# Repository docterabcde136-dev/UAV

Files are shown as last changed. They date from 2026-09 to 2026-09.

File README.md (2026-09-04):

# UAV

## 项目简介

基于 STM32F405 的四轴无人机飞控系统，集成 LQR 与 PID 控制算法、姿态解算、FreeRTOS 实时操作系统、DShot 电调驱动、IMU 多传感器融合（陀螺仪/加速度计）、蓝牙与 PS2 遥控、光流定高，配套 MATLAB/Simulink/Simscape 仿真验证与 Keil MDK 嵌入式开发完整资料。

STM32F405-based quadcopter flight control system integrating LQR and PID control algorithms, attitude estimation, FreeRTOS real-time operating system, DShot ESC driver, IMU multi-sensor fusion (gyroscope/accelerometer), Bluetooth and PS2 remote control, and optical flow altitude hold, with complete MATLAB/Simulink/Simscape simulation verification and Keil MDK embedded development resources.

## 目录结构

```

无人机 /

├── 四轴无人机 /

│   ├── 程序源码 /

│   │   ├── keil 工程 /                 # Keil MDK 工程（LQR / PID / 电调例程）

│   │   └── MATLAB 程序 /        # MATLAB 仿真与算法验证

│   ├── 传感器手册 /                   # 各传感器数据手册

│   ├── 原理图 /                          # 飞控板原理图

│   ├── 飞行器油门拟合文件 /    # 油门曲线拟合数据

│   └── *.pdf                               # 开发手册、使用手册、调试经验

└── 初学者复刻 /                        # 入门级复刻资料与烧录工具

```

## 开发环境

- **IDE**：Keil MDK 5

- **芯片**：STM32F405RGT6

- **系统**：FreeRTOS

- **仿真**：MATLAB / Simulink / Simscape

## 大文件下载

以下文件体积较大，未纳入 git 版本管理，请通过百度网盘下载：

| 文件 | 大小 | 说明 | 下载链接 |

| LQR.avi | 353 MB | Simscape 四轴飞行器 LQR 控制仿真演示视频 | https://pan.baidu.com/s/13S9hLy8eEmibUFdEDGfKNA?pwd=5m56  |

| 无人机配套软件工具.zip | ~116 MB | 串口调试助手、虚拟串口、无线烧录助手、蓝牙透传软件、FlyControl APP 等 | https://pan.baidu.com/s/14PjQdfBVtd2VivTcREuWbg?pwd=459s  |

## 编译说明

1. 使用 Keil MDK 5 打开 `程序源码/keil工程/LQR/MDK-ARM/Fly_LQR.uvprojx`

2. 选择对应目标编译生成固件

3. 使用无线烧录助手或 ST-Link 烧录到飞控板

## 注意事项

- 编译产物（`.o`、`.crf`、`.axf` 等）已通过 `.gitignore` 过滤，clone 后需自行编译

- 第三方软件工具不纳入 git，请到上方百度网盘链接下载

- 仿真视频不纳入 git，请到上方百度网盘链接下载

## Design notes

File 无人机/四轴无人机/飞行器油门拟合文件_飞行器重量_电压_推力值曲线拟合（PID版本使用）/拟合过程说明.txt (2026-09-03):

1.通过电子秤，采集飞行器在 10V、10.5V、11V、11.5V、12V、12.5V 的电压下，油门在 48 - 1148 范围内的推力值（其中48-1148油门，每间隔50油门采集1次推力参数）

2.将上述采集到的数据表，写入python文件进行拟合，主要输出以下公式：输入当前的电压值、输入的飞行器重量，计算出需要多少油门值才可以保持飞行器的推力与自身重量持平。

3.安装好python所需的各类库文件，运行py文件，输出拟合公式。

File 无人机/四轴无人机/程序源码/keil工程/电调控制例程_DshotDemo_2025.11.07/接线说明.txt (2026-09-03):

本例程使用STM32F405单片机作为案例
PC6  --- 电调1 PWM信号引脚
PC7  --- 电调2 PWM信号引脚
PC8  --- 电调3 PWM信号引脚
PC8  --- 电调4 PWM信号引脚

本案例中电调固件版本为BlueJay v0.21

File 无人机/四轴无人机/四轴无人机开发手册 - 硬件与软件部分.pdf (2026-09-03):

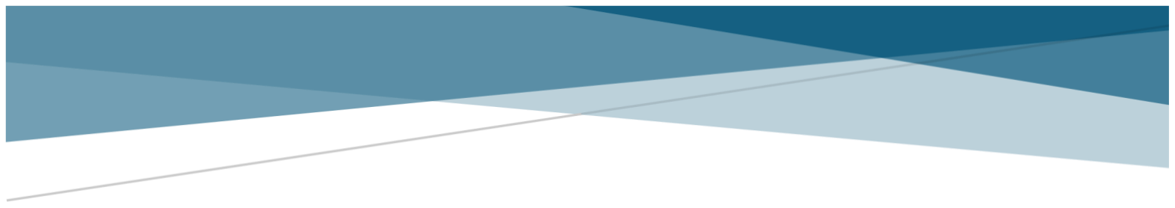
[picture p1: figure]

# STM32F4 四轴飞行器开发手册

## 硬件与软件部分

### 光电 209 实验室

摘要

本文档对四轴飞行器的硬件设计、软件框架作讲解与介绍，助力于读者能快速理解飞 行器的软件结构和所有功能的实现原理。文档内容不包括四轴飞行器的控制原理与算 法部分，该部分内容请查看资料内《四轴无人机开发手册 - 原理与算法部分》文档。

目录

1.软件资源概览

本产品使用到的主控芯片为 STM32F405RGT6，使用到的资源以及作用如 下介绍：
ADC1_IN1: ADC1 通道 1，用于采集电池的输入电压，监测电池电量 TIM6: 计数定时器，用于 FreeRTOS 系统调试
TIM8: 定时器 8 所有通道，PWM 输出，用于驱动电调控制电机 TIM7: HAL 库时基
SysTick: FreeRTOS 系统时基
I2C1: | 硬件 IIC1，用于与陀螺仪通信，获取陀螺仪数据
USART1: | 调试串口，同时也是程序烧录口
USART2: | 串口 2，与雷达模块通信
USART3: | 串口 3，与光流模块通信，获取光流传感器数据
USART4: | 串口 4，与蓝牙模块通信，用于手机 APP 控制与查看波形功能
UART5: | 串口 5，与激光测距模块 STP23L 通信，获取高度信息
USB_OTG_FS: | 全速 USB 接口，用于获取 PS2 手柄数据
GPIO: | 普通 GPIO,用于 LED、蜂鸣器、OLED 等功能。其中 OLED 为预留
接口。

2.软件框架设计说明

为保证四轴飞行器运行的实时性以及 CPU 资料的合理分配使用，整体软件 框架基于 FreeRTOS 设计，运行框架如图所示：

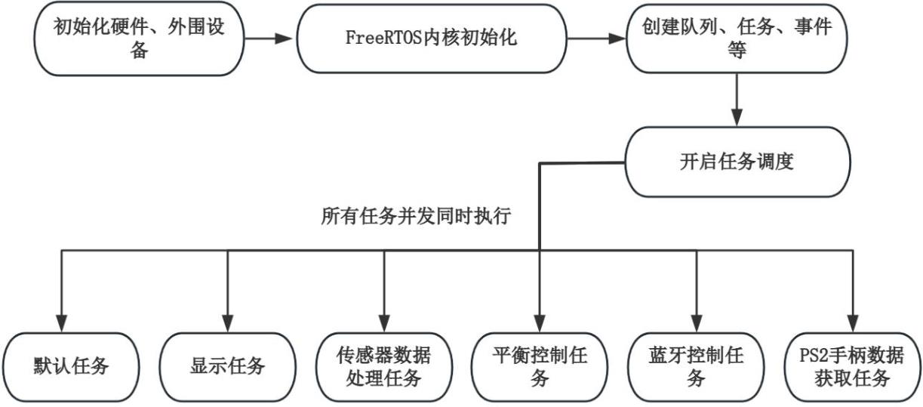
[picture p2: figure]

对于具体的任务优先级配置，可查看文件 freertos.c 中的 MX_FREERTOS_Init()函数。在任务创建并开始调度后，每个任务将会同时运行。

2.1 默认任务

在默认任务内，会创建 USB 手柄接收任务，并使能各个传感器的 DMA 接 收，以便实时获得数据。在默认任务完成后，会删除自身以节省资源空间。任务

名称为 voidStartDefaultTask(void*argument)。整体运行逻辑如下图所示。

2.2 显示任务

显示任务主要负责将飞行器的实时状态进行上传。可以通过程序来选择上传 到手机 APP 或 minibalance 上位机。上传的数据包括电池电压、欧拉角、飞行高 度等数据，具体内容可以在程序中进行自定义调节。显示任务函数名为

ShowTask(void*param)。
由于显示任务为调试属性，所以将其优先级配置为较低。只有在其他控制任 务阻塞时，才会执行显示任务。其任务逻辑如下图所示。

2.3 传感器数据处理任务

该任务主要负责接收解析激光测距模块、雷达模块的数据。其触发机制如下： 空闲时该任务是阻塞状态，不会运行。当测距模块或雷达模块数据到来时，由 DMA 将数据放入队列中，当队列中存在数据时，调度器会唤醒该任务进行数据 处理与解析。解析后的数据将会提供给控制任务使用。

任务名称为 voidSensorHandleTask(void*param)，其逻辑如下图所示。

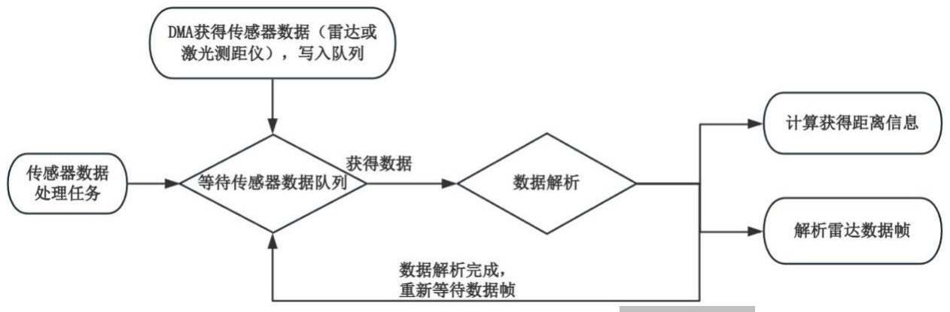
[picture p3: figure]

其中 STP23L 激光测距模块解析数据的过程在 | bsp_stp23L.c | 文件内。雷达解

析数据过程在 bsp_stl06n.c 文件内。

2.4 平衡控制任务

该任务是四轴飞行器控制的核心部分，内部包含了陀螺仪数据的获取与处理、 高度数据的使用与处理、雷达数据使用与处理、LQR 控制器、四轴飞行器的状态 设置与获取等内容。
值得注意的是，该任务为主要的核心部分，以 200Hz 的频率运行。四轴的平 稳控制需要保证该任务频率足够准确。在设计其他模块或任务时，均需要考虑任 务优先级以及某些任务是否长时间占用 CPU 时间等问题。同时该任务内也加入 了一个外部的频率检测器，可以用过该检测器来检测任务频率是否准确，其内容 如下所示：

g_readonly_BalanceTaskFreq=debug->UpdateFreq(&debugPriv);
如果加了其他 DIY 传感器或者功能，可以通过监测

g_readonly_BalanceTaskFreq 变量的输出来检查当前的任务频率是否满足要 求，正常该值输出为 200，单位是 Hz。若为其他数值，则说明控制任务的频率受 到了干扰。

控制任务的名称为 voidbalance_task(void*param)，其运行逻辑如下所示：

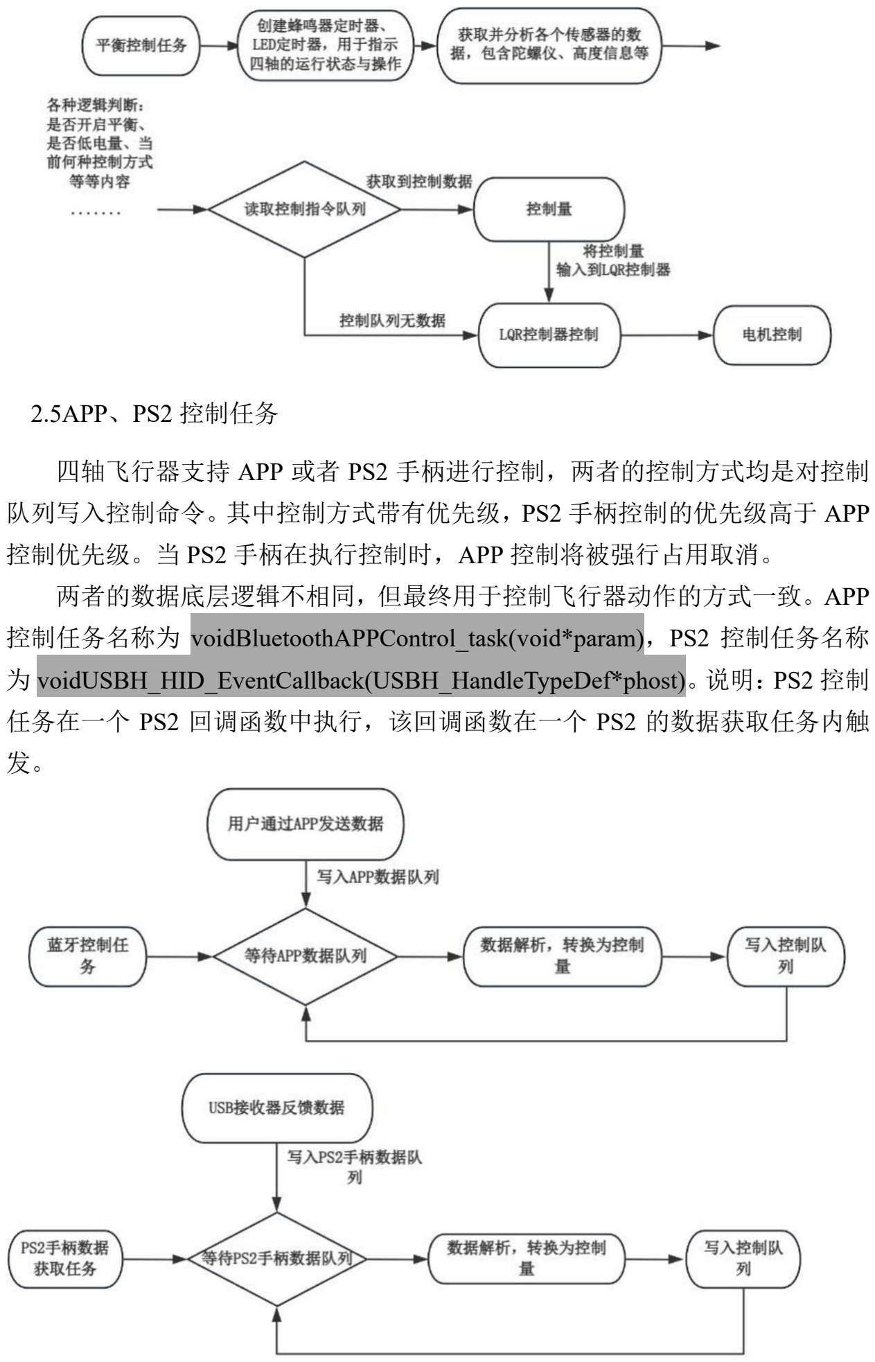
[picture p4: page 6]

2.5APP、PS2 控制任务

四轴飞行器支持 APP 或者 PS2 手柄进行控制，两者的控制方式均是对控制 队列写入控制命令。其中控制方式带有优先级，PS2 手柄控制的优先级高于 APP 控制优先级。当 PS2 手柄在执行控制时，APP 控制将被强行占用取消。 两者的数据底层逻辑不相同，但最终用于控制飞行器动作的方式一致。APP

控制任务名称为 voidBluetoothAPPControl_task(void*param)，PS2 控制任务名称

为 voidUSBH_HID_EventCallback(USBH_HandleTypeDef*phost)。说明：PS2 控制 任务在一个 PS2 回调函数中执行，该回调函数在一个 PS2 的数据获取任务内触 发。

2.6 雷达数据处理任务

在传感器数据处理任务中，会判断是否完成 1 圈雷达数据的接收。在完成 1 圈雷达数据接收后，将会把数据写入队列，让雷达数据处理任务运行，雷达数据 处理任务的内容是将雷达的数据通过算法处理成飞行器的坐标数据。

雷达接收的任务名称为 voidSensorHandleTask(void*param)，雷达点云处理算

法任务名称为 voidCoordinateHandleTask(void*param)。

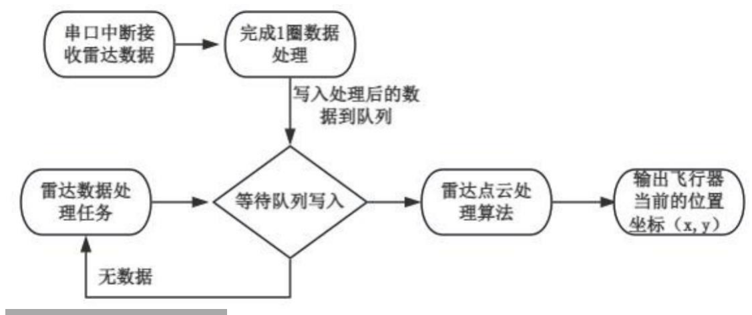
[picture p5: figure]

CoordinateHandleTask，避障功能，具体表现为：雷达的前后左右四个方向， 有一个方向有障碍物靠近时，飞行器就会往相反的方向运动，并发出蜂鸣器提示。 此功能为实验性功能，后续可以根据现有内容继续优化，已完成更好的避障效果。

2.7 光流数据处理中断

光流传感器的原始数据直接在串口中断内进行解析，频率 50Hz。具体过程 为：光流完成初始化后，将通过一定的格式主动上报数据，每一帧数据上报完成 后，就会进入串口空闲中断，在此中断内解析处理 DMA 搬运的数据。 拿到原始数据后，在平衡控制任务将原始数据与陀螺仪数据进行融合增加稳 定性，最终把融合后的数据用于位置控制。

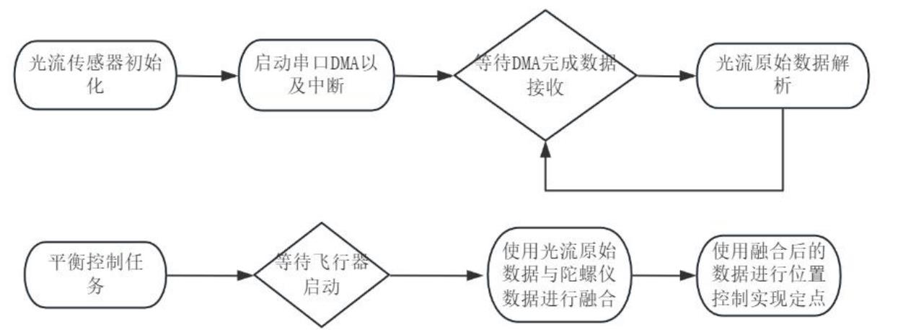
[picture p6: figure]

3.硬件与软件实现细节

3.1 陀螺仪

1 陀螺仪电路设计

陀螺仪是四轴飞行器的核心传感器，本产品采用 InvenSense 公司的 ICM20948，原理图如图所示。其中 SCL、SDA 连接至硬件 IIC1 接口，中断输出 引脚 INT1 连接到普通的 IO。在本产品中未使用陀螺仪的中断功能，仅获取其原

始数据使用。

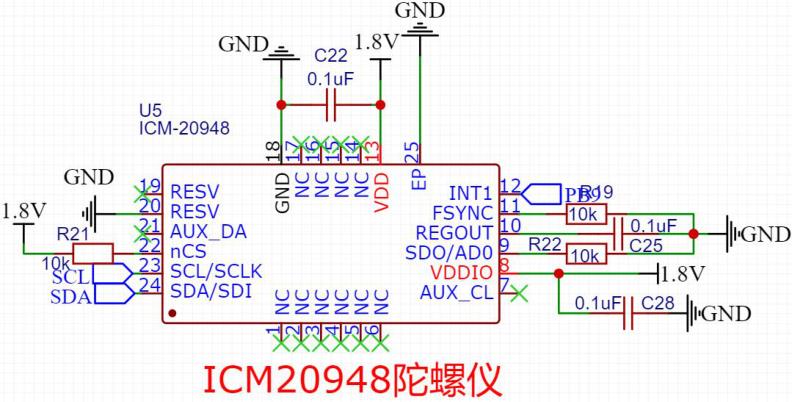
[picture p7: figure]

2 陀螺仪数据获取

ICM20948 最大支持 400kHz 的 IIC 通信速率，故 IIC 总线做如下图配置，更

多细节可自行查看 ioc 配置文件：
为了方便移植以及使用模拟 iic，在软件中对 iic 接口做了以下的封装，在该

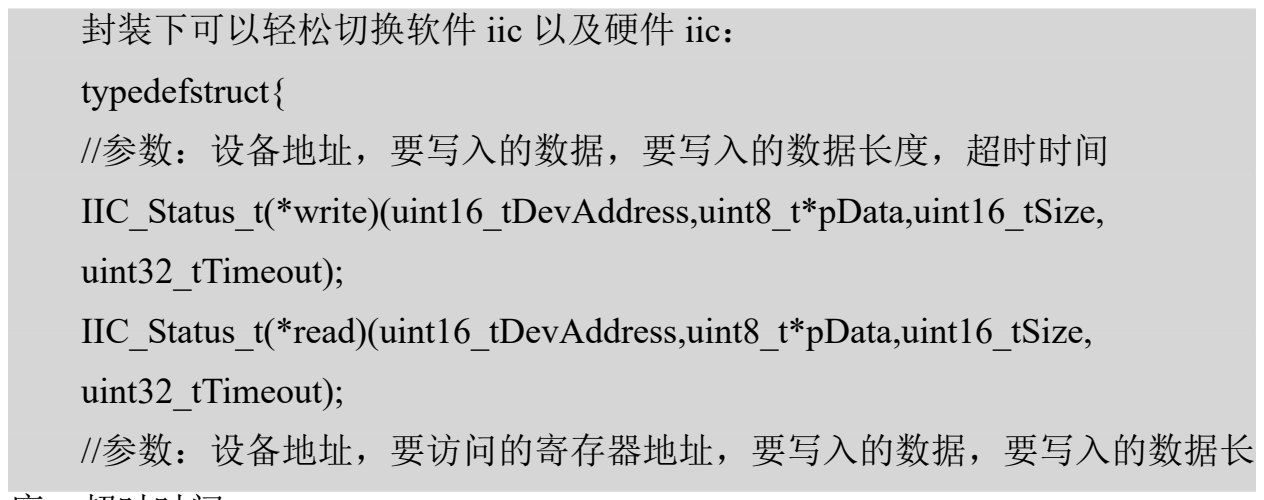
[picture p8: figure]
封装下可以轻松切换软件 iic 以及硬件 iic：; typedefstruct{; //参数：设备地址，要写入的数据，要写入的数据长度，超时时间; uint32_tTimeout);; //参数：设备地址，要访问的寄存器地址，要写入的数据，要写入的数据长

IIC_Status_t(*write)(uint16_tDevAddress,uint8_t*pData,uint16_tSize,

IIC_Status_t(*read)(uint16_tDevAddress,uint8_t*pData,uint16_tSize,

度，超时时间

硬件初始化完毕 iic 后，再将硬件 iic 的接口函数挂载到上述自定义接口中， 即可完成 iic 的所有初始化步骤。至此已经可以顺利使用 iic 与陀螺仪进行通信

了，初始化部分可在 bsp_imc.c 文件内查看函数 staticuint8_t ICM20948_Init(void)。 完成 imu 初始化后，后续主要通过两个函数来实现 imu 的原始数据以及姿 态解算：

staticvoidImuUpdate(IMU_DATA_t*data)：获取 IMU 的 9 轴原始数值

staticvoidattitudeUpdate(IMU_DATA_timudata,ATTITUDE_DATA_t*attitude) ： 使用 imu 的原始值进行姿态解算，获得欧拉角。该函数使用显示互补滤波算法， 内部的实现细节可查看《四轴无人机开发手册-原理与算法部分》文档。

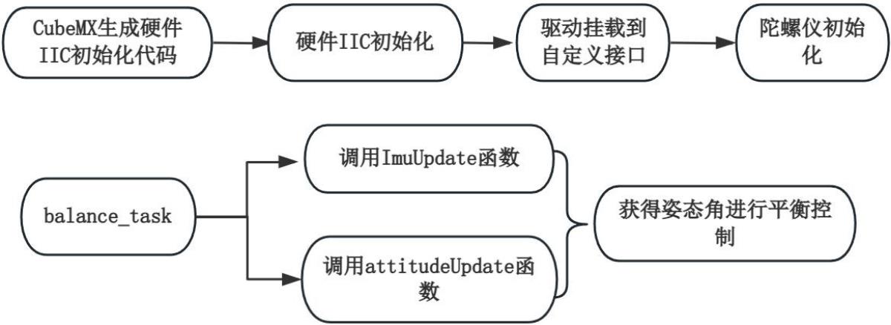
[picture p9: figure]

3.2 激光测距

激光测距模块使用 STP23-L，该传感器的详情在资料文件夹《传感器手册》 中可查看。STP23-L 通过串口输出数据，波特率为 230400，数据以点云的形式输 出。1 个点云数据内容包含测量距离、信号强度、置信度等信息。其输出频率为 10Hz，1 帧数据内包括 12 个点云信息。

高度数据通过串口接收，最终通过 bsp_stp23L.c 文件内的

stp23L_getdistance_callback 进行接收以及数据解码。其接收过程如下图所示：

3.3 电量检测

电量检测主要通过测量电池的输入电压来实现。本产品使用磷酸铁锂电池电 池，标称电压 12.6V，截至电压 10V。在飞行器运行的过程中，由于飞行器 供电线长的关系(2 米)，实测压降为 0.8V 左右。例如飞行器电池电压有 10.8V， 在飞行器运行期间，能够输入到飞行器内的电压为 10.8-0.8=10V。为了保证有足

够的电量进行飞行，在程序内部设定了电量低的保护，当电池电压低于 10.8V 时， 将不允许启动。

1 电压测量电路实现

在电池输入处，串联了一个 100k 和 10k 的电阻实现分压，并使用 ADC 相 关的引脚进行模拟量采集，此处为 PA1，如下图所示。 根据简单的分压公式可得知，测量点处的电压为：Vin=VADC×11
ADC 测量引脚电压范围在 0~3.3V，对应 ADC 采样值 0~4095，可得出最终

的输入电压公式为：Vin=ADC 采样原始值/4095×3.3×11

2 程序实现

为确保不影响系统的实时性，ADC 配置为软件触发、连续采集，并使用 DMA

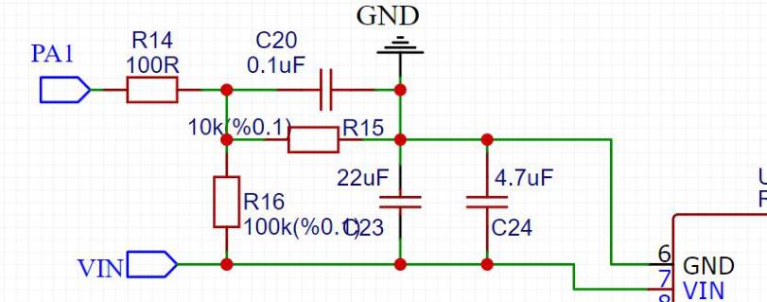
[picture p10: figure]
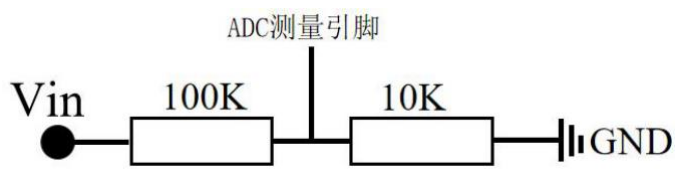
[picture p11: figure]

循环搬运数据，不占用 CPU 资源。为保证采样的准确性，采用时配置了最大的 采样周期，同时让 DMA 搬运到一个长度为 80 的数组中，最终取平均值计算。 具体的配置可查看 ioc 配置文件，程序的实现在 bsp_adc.c 文件内。最终的输入

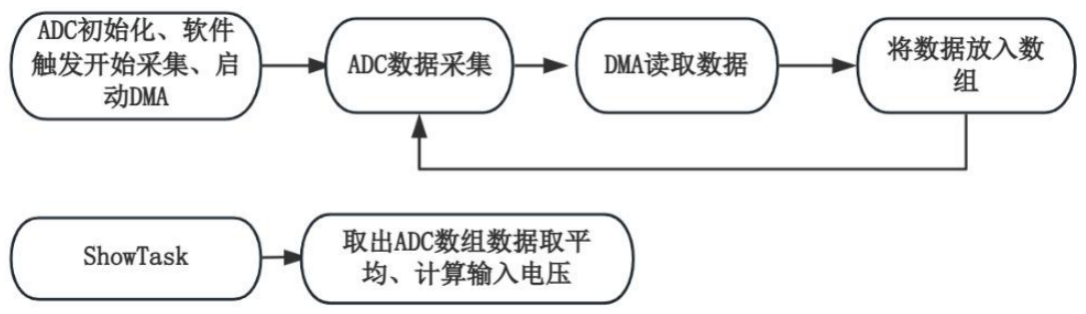
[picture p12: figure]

电压计算由显示任务完成，其处理的内容主要是在数组中取出数据取平均，然后 根据上述提到的公式计算出输入电压。

3.4 电机控制

1 硬件部分

电机控制的硬件部分主要是引出 TIM8 的 4 个通道引脚，作为一个接口与电

调连接，如下图所示。飞控与电调的连接如下：

PC6---E1（E1~E4 为电机控制信号线，ADC 用于电调电流采集）

PC7---E2

PC8---E3

PC9---E4

PB1---ADC
电调负责的工作：将主控芯片发过来的信号解析，最终转换为油门的大小， 控制无刷电机旋转。
飞控板的工作：将 LQR 控制器输出的信号转化为油门值，通过 PWM 引脚

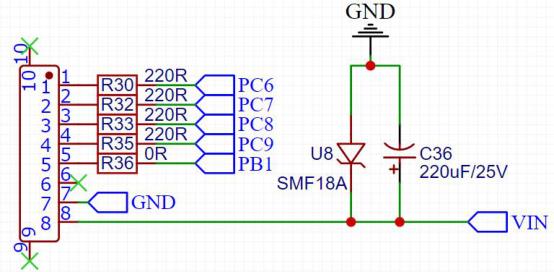
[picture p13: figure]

发送到电调。

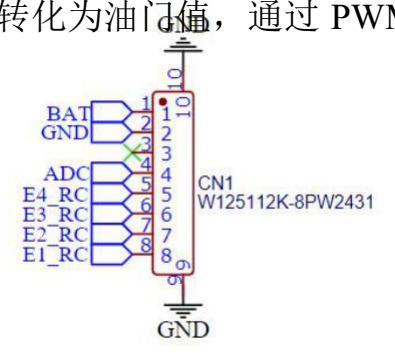
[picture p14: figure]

飞控板与电调通信的协议为 Dshot300。下面简述 Dshot 协议的一些基本内

容：目前 Dshot 协议常见类型有 Dshot150、Dshot300、Dshot600 和 Dshot1200。 后面的数字代表在通信过程中，每秒传输多少 kbit，类似于串口的波特率。例如 本产品中使用 Dshot300 协议，代表飞控每秒可传输 300kbit 数据到电调。
在 Dshot 协议中，一个周期脉冲表示一个 bit，发送的数据位 0 或者 1 则通 过一个周期内的占空比来表示。所以 Dshot 与 PWM 有如下的关系：Dshot 协议 的速度类型决定 PWM 的频率，Dshot 发送的数据位 0 或者 1 决定 PWM 的占空 比。
Dshot 协议中的 0 或者 1 的占空比对应关系如下图：

逻辑 1 对应 PWM 占空比 75%

逻辑 0 对应 PWM 占空比 37.5%

Dshot 协议在通信时，一帧数据共有 16 个 bit 构成，其中前 11 位是油门信 号，可表示的范围是 0~2047。第 12 位是命令请求或者命令设置使能位，后 4 位

是校验位。
油门信号：在油门值中，0~47 的数值范围用于一些命令的设置，比如设置电 调的 LED 指示灯、设置电机的旋转方向等功能。所以真实的油门值信号从 48 开 始，48 表示最低油门，电机不会旋转；2047 表示满油门，电机将会以最大速度 运行。
命令请求位/设置使能位：如果需要对电调进行设置时，例如上述提到的修 改电机旋转方向或 LED 指示灯，则需要把这个位置 1。若需要对电机进行控制 （设置 48~2047 油门值），需要将此位设置为 0。
校验位：校验位是将前 12 位数据分为 3 组，每组 4bit，进行异或校验。 假设当前有一个 12 位的 SendData 数值需要校验，则校验方式为：

csum=(SendData^(SendData>>4)^(SendData>>8))&0xf
下面一帧完整的 dshot 数据演示，假设当前需要设置油门值

1046(10000010110b)，则命令使能位应该位 0，则可计算到校验位为 0x06(0110b), 数据帧如下图所示：

更多 Dshot 内容,推荐参考网址：DSHOTintheDark–dmrlawson (https://dmrlawson.co.uk/index.php/2017/12/04/dshot-in-the-dark/)
在简单了解上述 Dshot 的通信协议与原理后，就可以对飞控板进行定时器的 配置了。首先是 PWM 的配置频率，这里使用的是 Dshot300 协议，速率为 300kbit/s，

也就是 PWM 每秒输出 300k 个脉冲，故 PWM 配置为 300000Hz。
飞控板使用的是 TIM8 作为通信的定时器，其主频为 168MHz，为了方便计 算，将定时器的预分频系数配置为 0。可算的自动重装载值配置应为 559。

将 TIM8 配置为 PWM1 输出，向上计数。要实现发送 dshot 的 0 和 1 指令 时，只需要修改定时器的 CCRx 寄存器即可。当需要发送逻辑 1 时，可通过配置 对应通道的 CCRx 寄存器输出 75%的占空比；需要发送逻辑 0 时，配置对应通道 的 CCRx 寄存器输出 37.5 占空比。

根据上述的配置，已经可以正确的向电调发送 0 和 1 的数据位了，此时需要 一个函数，直接将需要发送的油门值进行解析，然后通过 PWM 的形式发送到电 调中。本产品使用 DMA 的方式，将解析后的数据搬运到定时器对应通道的 CCRx

寄存器内，实现与电调通信，具体内容可在 bsp_dshot.c 文件内的 pwmWriteDigital 函数查看。其核心部分是将 0 与 1 通过 CCRx 寄存器的值表示，以及通过 DMA

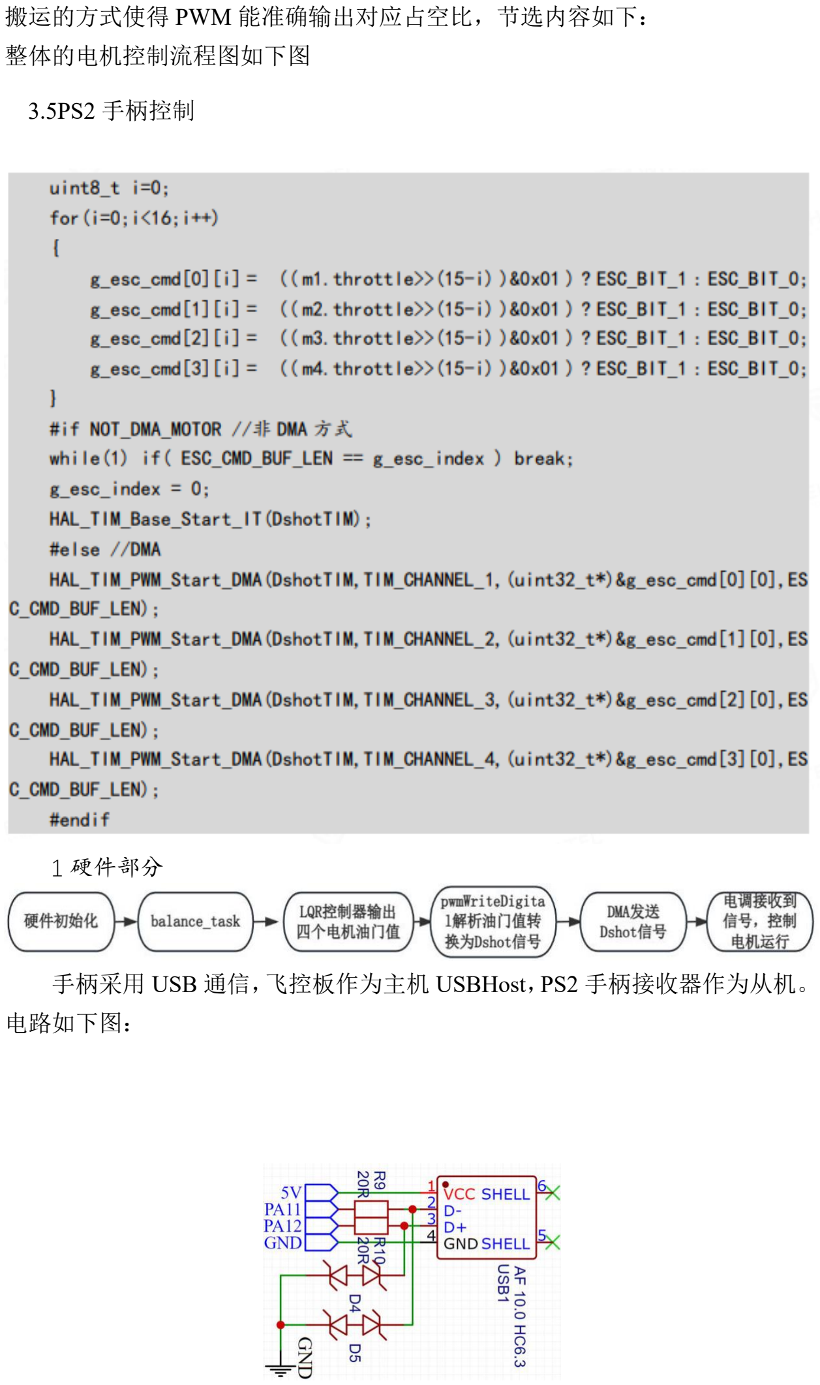
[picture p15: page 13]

搬运的方式使得 PWM 能准确输出对应占空比，节选内容如下： 整体的电机控制流程图如下图

3.5PS2 手柄控制

1 硬件部分

手柄采用 USB 通信，飞控板作为主机 USBHost，PS2 手柄接收器作为从机。 电路如下图：

2 软件部分

在 CubeMX 中，将 USB_OTG_FS 全速设备使能，如下图所示：

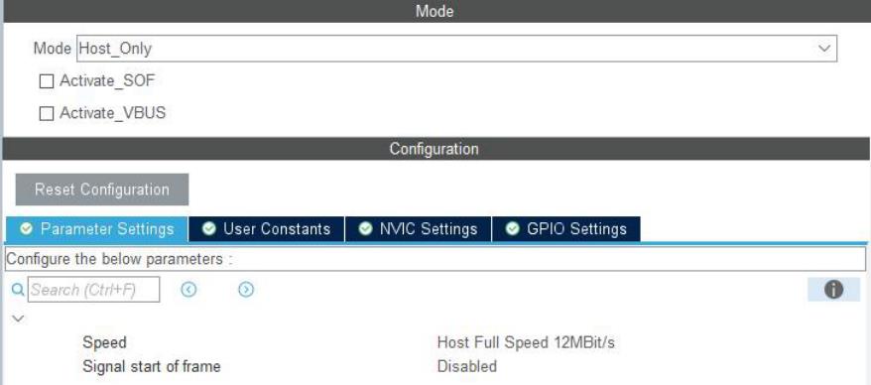
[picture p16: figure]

使能 USBOTG 后，在中间件里面配置 USB 设备的类型，手柄类型是 HID。 本产品使用的无线 PS2 手柄内置两种模式，一种为 PC 模式，一种 Android 模式， 两种模式是不同的 HID 设备类型，所以在最大支持的 HID 设备类中，配置为 2。 另外 PS2 设备输出的数据长度较长，需要给存放数据的 Buffer 配置较大长度， 这里为 1024bytes。此外使用到了 FreeRTOS，所以在 RTOS 配置栏需要配置优先 级，以及任务的栈大小，如下图所示。

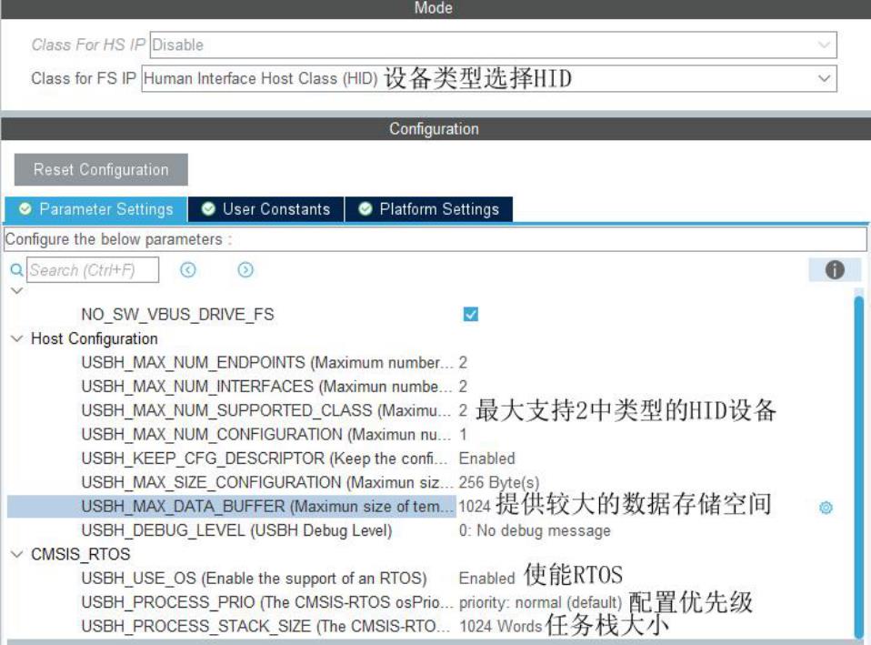
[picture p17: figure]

完成 CubeMX 配置后，需要手动创建 PS2 的 HID 类，并提供接口初始化函 数、数据请求函数、数据解析函数等内容，此部分内容可参考官方提供的

usbh_hid_keybd.c 或 usbh_hid_mouse.c 学习。PS2 手柄相关的细节位于 bsp_ps2.c 文件内。在创建完 PS2 手柄的 HID 类后，需要将设备注册到 USB HOST，注册

以及初始化过程均在 | usb_host.c | 文件 | MX_USB_HOST_Init | 函数完成。该函数在
默认任务中调用，整体的流程如下图所示：

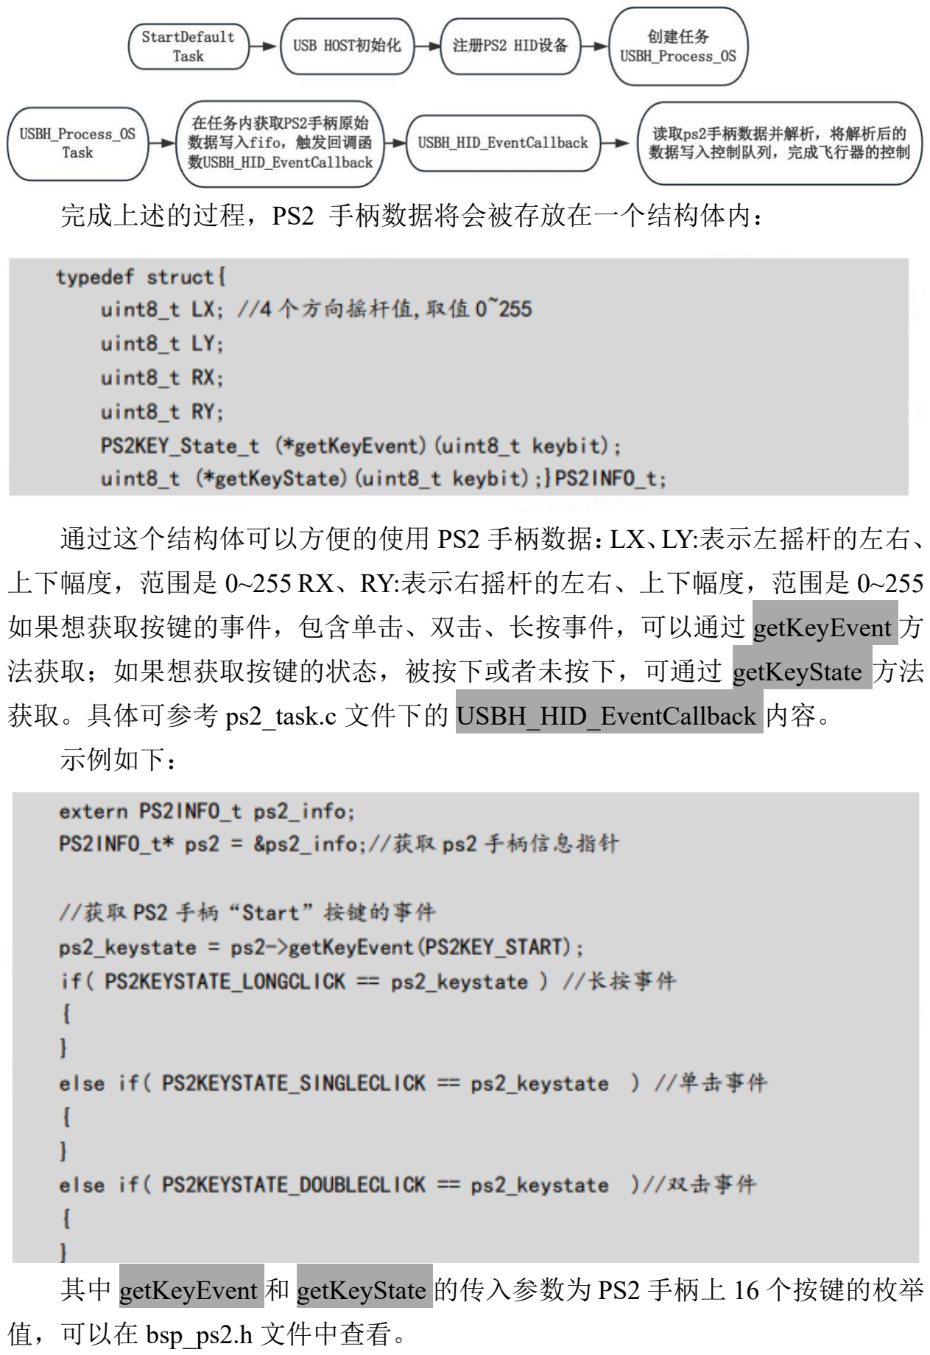
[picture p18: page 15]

完成上述的过程，PS2 手柄数据将会被存放在一个结构体内：

通过这个结构体可以方便的使用 PS2 手柄数据：LX、LY:表示左摇杆的左右、 上下幅度，范围是 0~255 RX、RY:表示右摇杆的左右、上下幅度，范围是 0~255 如果想获取按键的事件，包含单击、双击、长按事件，可以通过 getKeyEvent 方
法获取；如果想获取按键的状态，被按下或者未按下，可通过 | getKeyState | 方法

获取。具体可参考 ps2_task.c 文件下的 USBH_HID_EventCallback 内容。 示例如下：

其中 getKeyEvent 和 getKeyState 的传入参数为 PS2 手柄上 16 个按键的枚举 值，可以在 bsp_ps2.h 文件中查看。

3.6APP 控制

1 硬件部分

APP 通信采用的是蓝牙透传的方式，通过串口 3 与蓝牙模块连接，完成数据 透传。电路如下图所示：

2 软件部分

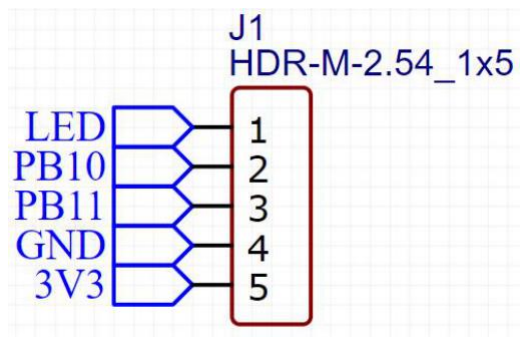
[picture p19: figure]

蓝牙模块的出厂波特率为 230400，所以在 CubeMX 中对串口 3 做对应的初 始化内容即可。在串口接收到手机 APP 数据时，会进入到串口的接收中断回调 函数，并将数据写入到队列中。队列收到数据后，调度器将唤醒

BluetoothAPPControl_task 任务进行 APP 数据的解析与处理。

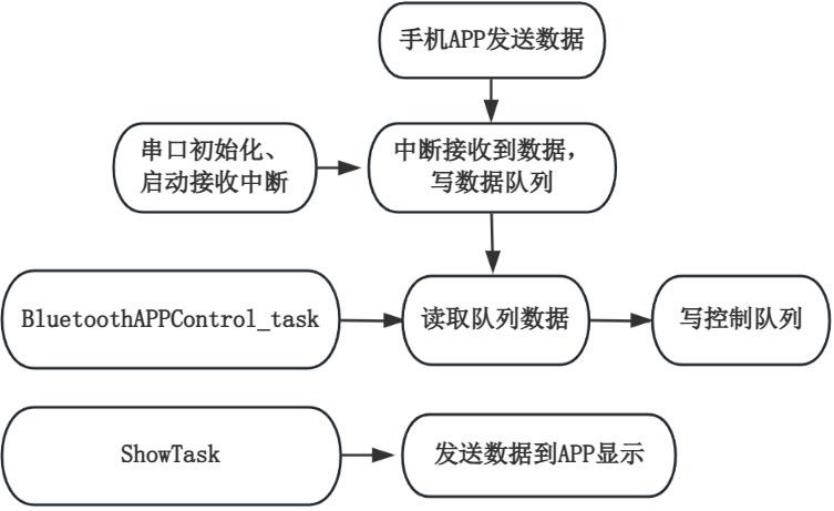
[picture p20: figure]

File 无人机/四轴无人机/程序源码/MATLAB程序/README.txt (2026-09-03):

1. 先运行任一版本的LQR.m文件后再运行SIMULINK\SystemBlock.slx系统框图仿真模型；
2. LQR_None.m：无定点辅助传感器版本；
    LQR_Lidar_and_OF.m：定点辅助传感器版本；
3. OpticalFlow文件夹里的程序为速度互补滤波的离线数值仿真。
4. SIMSCAPE文件夹为物理仿真内容（直接运行F570.slx文件即可）。

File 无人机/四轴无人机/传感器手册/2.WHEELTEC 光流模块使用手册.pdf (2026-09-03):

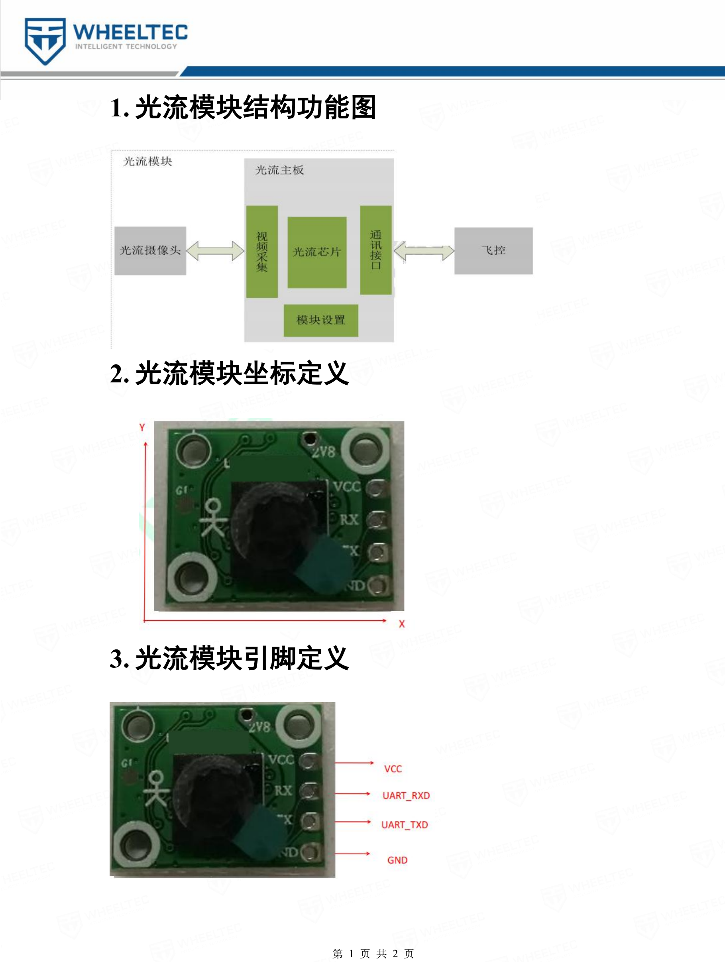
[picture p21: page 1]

第 1 页 共 2 页

### 1. 光流模块结构功能图

### 2. 光流模块坐标定义

### 3. 光流模块引脚定义

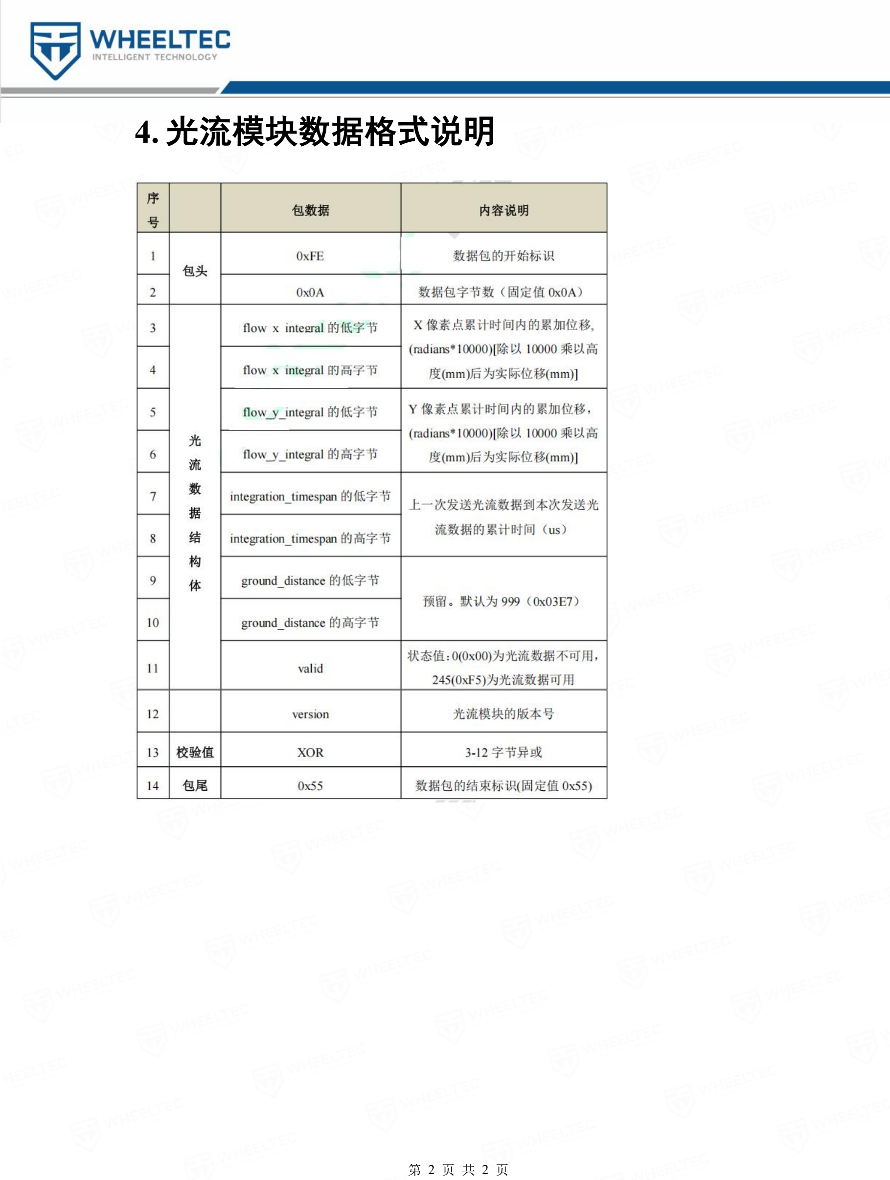
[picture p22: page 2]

第 2 页 共 2 页

### 4. 光流模块数据格式说明

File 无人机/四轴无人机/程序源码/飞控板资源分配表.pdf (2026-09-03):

## F570飞控板资源分配表

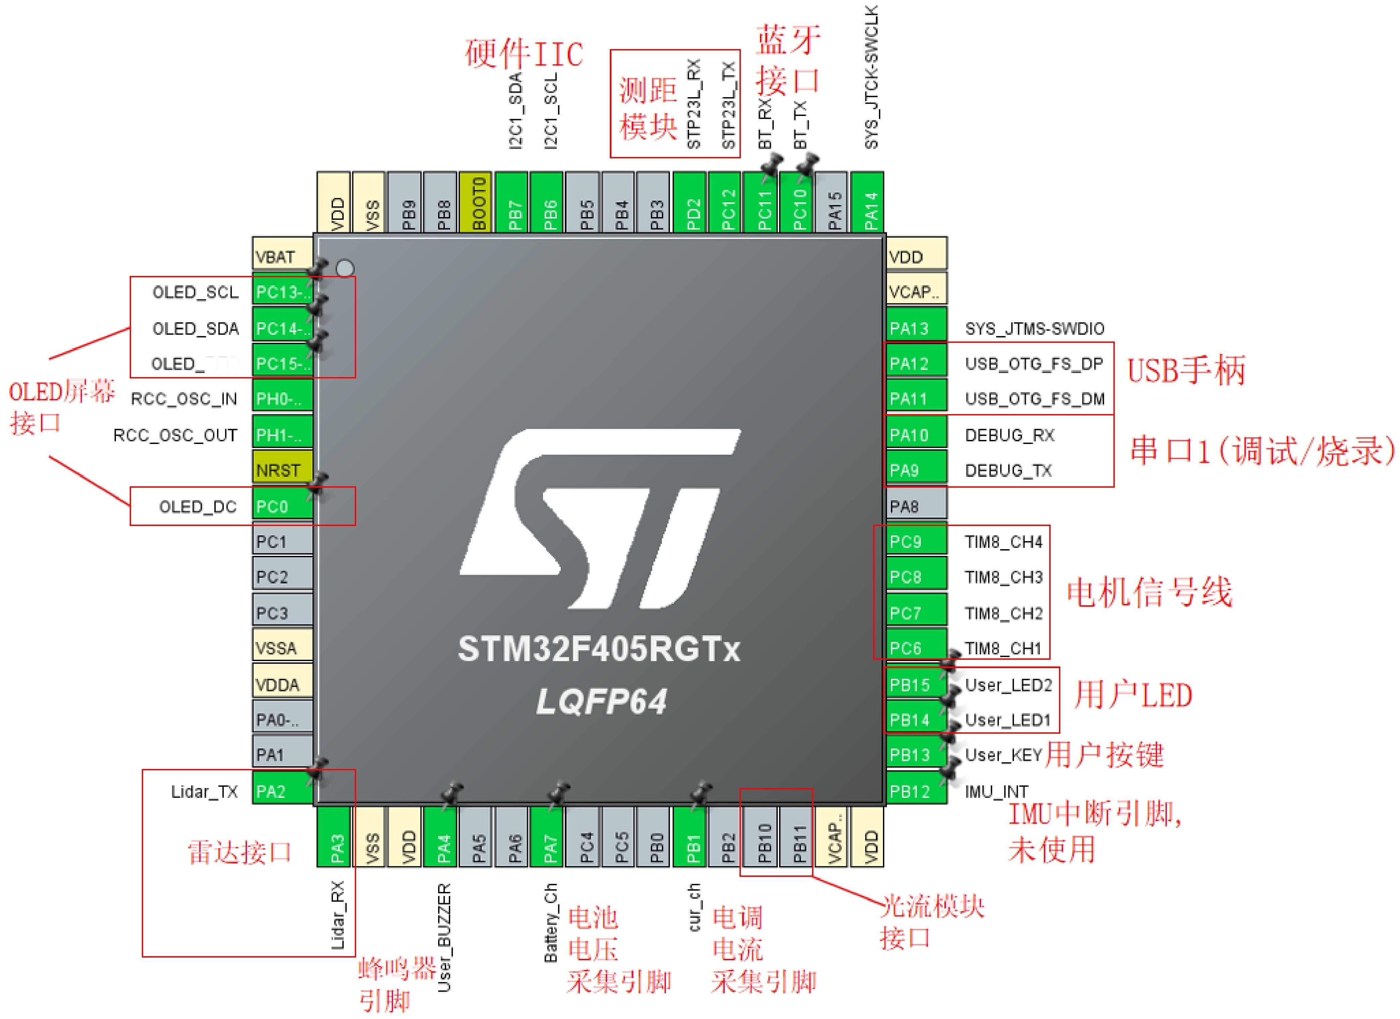
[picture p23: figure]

资源说明 | 功能 | IO编号
普通IO-LED | 指示LED | PB14、PB15
普通IO-蜂鸣器 | 操作提示 | PA4
串口1 | 调试、烧录 | PA9、PA10
串口2 | 雷达接口 | PA2、PA3
串口3 | 光流模块接口 | PB10、PB11
串口4 | 蓝牙接口 | PC10、PC11
串口5 | 测距模块，测量飞行高度 | PC12、PD2
硬件IIC | 陀螺仪通信引脚 | PB6、PB7
普通IO-陀螺仪中断 | 陀螺仪可配置内部中断，未使用 | PB12
定时器8 | 电机信号引脚，发送油门值 | PC6、PC7、PC8、PC9
USB HOST | 与PS2手柄通信 | PA11、PA12
普通IO-OLED | 预留OLED屏幕，引出接口(软SPI) | PC0、PC13、PC14、PC15
ADC1 | 电池电量检测 | PA7
ADC1 | 电调电流检测 | PB1

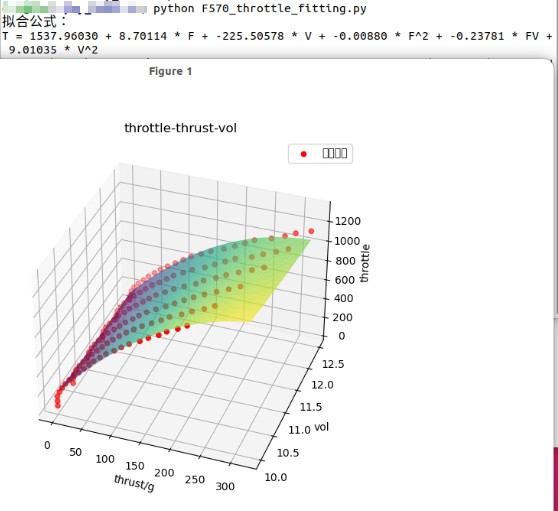
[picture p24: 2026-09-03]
无人机/四轴无人机/飞行器油门拟合文件_飞行器重量_电压_推力值曲线拟合（PID版本使用）/python文件执行结果.jpg

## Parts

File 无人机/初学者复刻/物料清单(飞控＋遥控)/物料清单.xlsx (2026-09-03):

飞控物料
序号 | 数量 | 物料类型 | 物料参数
1 | 5 | 0603贴片电容 | 4.7UF
2 | 10 | 0603贴片电容 | 100nF
3 | 2 | 0603贴片电容 | 20pF
4 | 1 | 0603贴片电容 | 2.2nF
5 | 1 | 0603贴片电容 | 10nF
6 | 5 | 0603贴片电容 | 10UF
7 | 1 | 0603贴片电容 | 22UF
8 | 1 | 0603贴片电容 | 4.7nF
9 | 1 | 肖特基二极管 | SS34
10 | 1 | 2*4P排母2.54mm间距 | PM254V-12-08-H85
11 | 1 | 功率电感 | 10uH
12 | 5 | 0603贴片LED | LED_0603-R（红色指示灯）
13 | 1 | 0603贴片LED | LED_0603-B（蓝色充电中）
14 | 1 | 0603贴片LED | LED_0603_Y（黄色充电完成）
15 | 1 | 0603贴片LED | LED_0603-G（绿色表状态）
16 | 4 | 端子（接电机） | ZX-MX1.25-2PWZ
17 | 3 | 1*4P排针（或弯针） | HEADER_1*4P
18 | 8 | NMOS | AO3400A
19 | 2 | PMOS | AO3401A_P
20 | 2 | 0603贴片电阻 | 5.1K
21 | 10 | 0603贴片电阻 | 10K
22 | 6 | 0603贴片电阻 | 2K
23 | 2 | 0603贴片电阻 | 2.2K
24 | 8 | 0603贴片电阻 | 100
25 | 2 | 0603贴片电阻 | 1K
26 | 1 | 0603贴片电阻 | 0.5
27 | 1 | 按键 | Key_SMD_3x4x2
28 | 1 | 开关 | SS-3235S-L1
29 | 1 | 主控芯片 | STM32F103C8T6
30 | 1 | 稳压芯片 | XC6206P332MR
31 | 1 | 晶振 | 8MHz
32 | 1 | 充电芯片 | TP4056
33 | 1 | 端子（接电池） | WAFER-PH2.0-2PZZ
34 | 1 | 陀螺仪芯片 | MPU-6050
35 | 1 | 升压芯片 | PW5100
36 | 1 | 充电typec口 | TYPE-C 6P
37 | 1 | OLED显示屏0.96寸 | 插接式（插入1*4P排母）
38 | 1 | NRF24L01模块 | 插接式（插入2*4P排母）
39 | 1 | 航模锂电池 | 600mah
40 | 4 | 8520空心杯电机 | 正反电机两对
遥控物料
序号 | 数量 | 物料类型 | 物料参数
1 | 1 | 0603贴片电容 | 4.7uF
2 | 8 | 0603贴片电容 | 100nF
3 | 2 | 0603贴片电容 | 20pF
4 | 4 | 0603贴片电容 | 10uF
5 | 1 | 0603贴片电容 | 10uF
6 | 1 | 0603贴片电容 | 22uF
7 | 1 | 0603贴片电容 | 4.7nF
8 | 1 | 肖特基二极管 | SS34
9 | 1 | 2*4P排母2.54mm间距 | PM254V-12-08-H85
10 | 1 | 功率电感 | 10uH
11 | 5 | 0603贴片LED | LED_0603-R
12 | 1 | 0603贴片LED | LED_0603-B
13 | 2 | 0603贴片LED | LED_0603-G
14 | 2 | 2*4P排母2.54mm间距 | HX PZ2.54-1x4P WZ
15 | 1 | 1*4P排母 | 2.54-1*4P母
16 | 2 | PMOS | AO3401A_P
17 | 12 | 0603贴片电阻 | 10K
18 | 1 | 0603贴片电阻 | 2K
19 | 3 | 0603贴片电阻 | 1K
20 | 2 | 0603贴片电阻 | 5.1K
21 | 1 | 0603贴片电阻 | 0.5
24 | 1 | 编码器 | EC12E2420301
25 | 9 | 按键 | Key_SMD_3x4x2
26 | 1 | 开关 | SS-3235S-L1
27 | 2 | 遥杆（16*16/10K） | 左右回中（油门）＋360度回中（方向）
28 | 1 | 充电芯片 | TP4056
29 | 1 | 端子（接电池） | WAFER-PH2.0-2PZZ
30 | 1 | 晶振 | 8MHz
31 | 1 | 升压芯片 | PW5100
32 | 1 | 主控芯片 | STM32F103C8T6
33 | 1 | 稳压芯片 | XC6206P332MR
34 | 1 | 充电typec口 | TYPE-C 6P
35 | 1 | OLED显示屏 | 插接式（插入1*4P排母）
36 | 1 | NRF24L01模块 | 插接式（插入2*4P排母）
37 | 1 | 锂电池 | 600mah

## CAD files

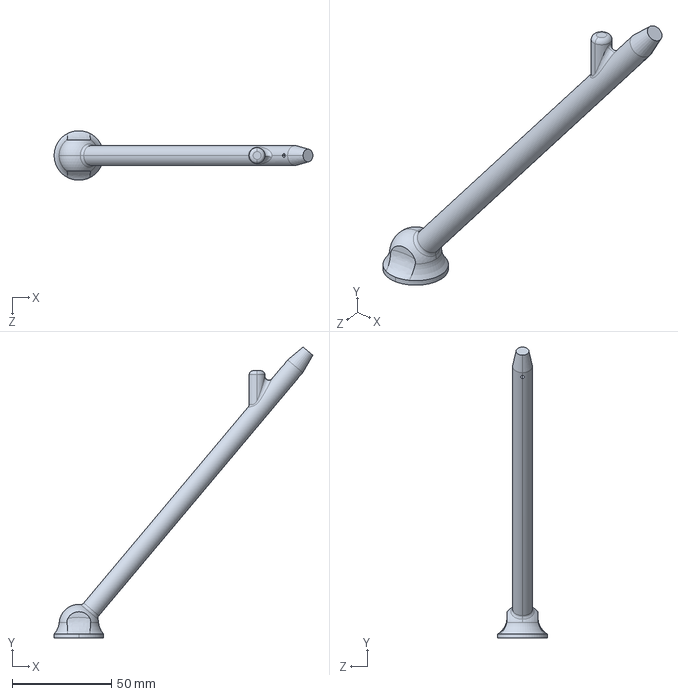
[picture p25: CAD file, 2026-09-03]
无人机/初学者复刻/模型(电机底座＋调试架)/调试架-脚杆(需6个).STEP
130.7 x 147.0 x 25.0 mm

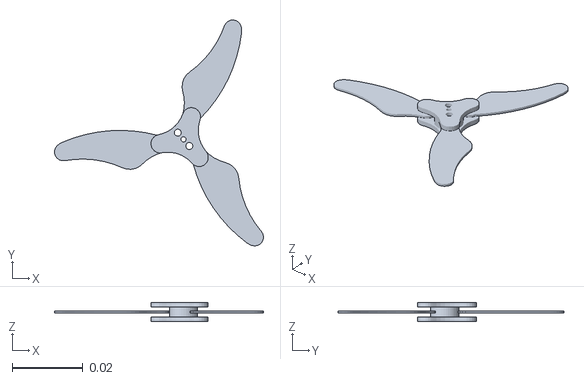
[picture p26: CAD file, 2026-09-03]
无人机/四轴无人机/程序源码/MATLAB程序/SIMSCAPE/meshes/Rotor1.STL
0.0592 x 0.0639 x 0.0055

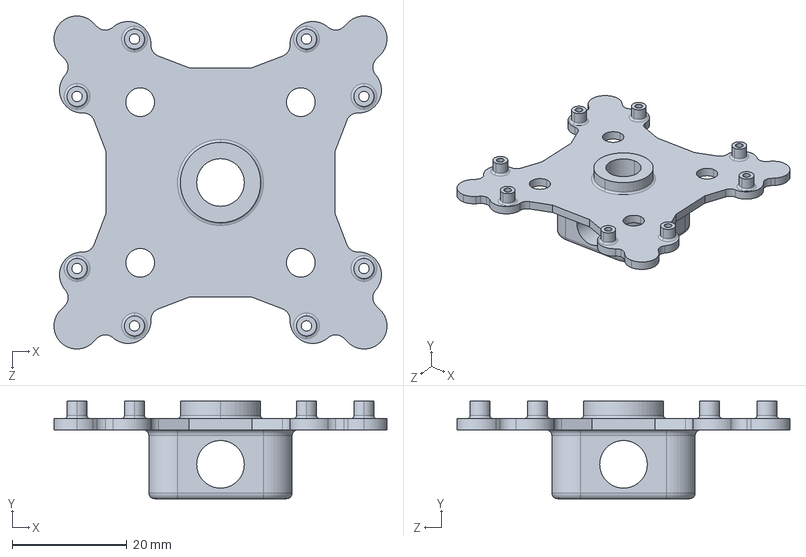
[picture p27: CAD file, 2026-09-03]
无人机/初学者复刻/模型(电机底座＋调试架)/调试架-飞控固定底座(需1个).STEP
58.1 x 17.0 x 58.1 mm

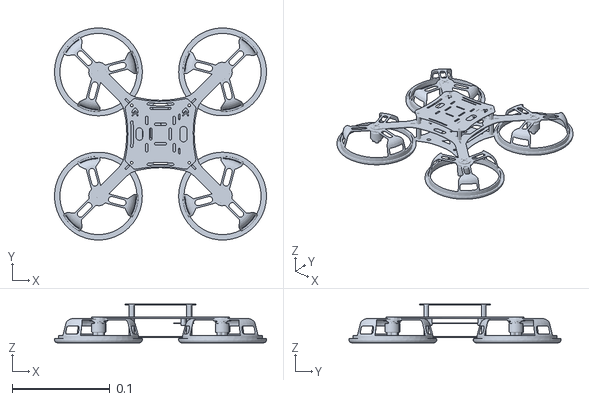
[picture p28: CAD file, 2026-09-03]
无人机/四轴无人机/程序源码/MATLAB程序/SIMSCAPE/meshes/Body.STL
0.217 x 0.217 x 0.0395

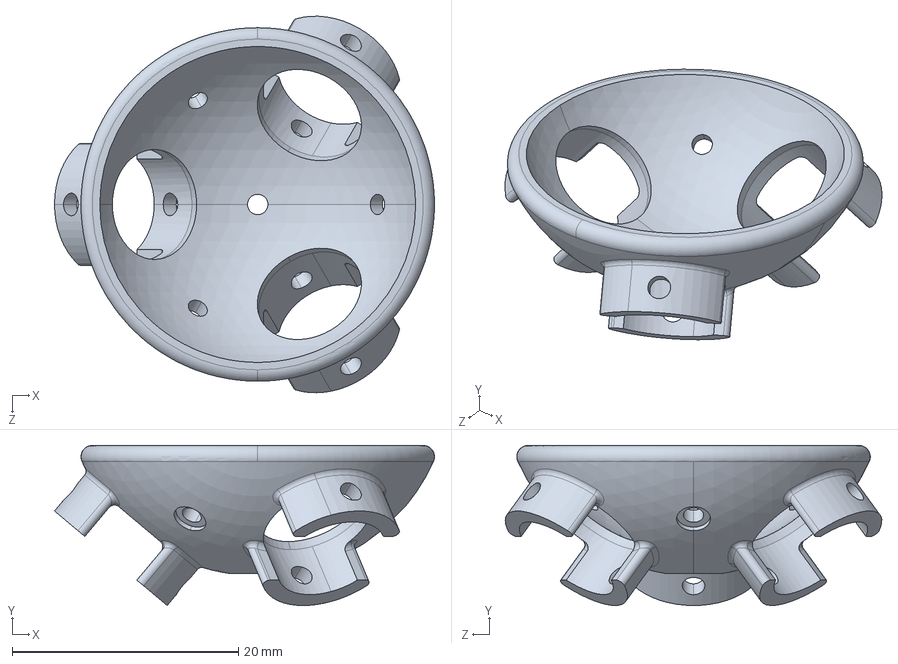
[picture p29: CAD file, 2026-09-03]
无人机/初学者复刻/模型(电机底座＋调试架)/调试架-脚杆固定件(需2个).STEP
33.6 x 14.1 x 33.3 mm

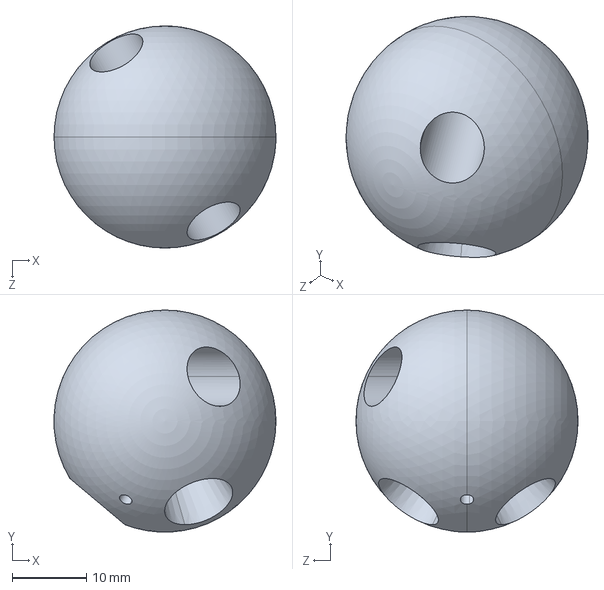
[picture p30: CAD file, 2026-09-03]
无人机/初学者复刻/模型(电机底座＋调试架)/调试架-脚杆连接球(需2个).STEP
30.0 x 30.0 x 30.0 mm

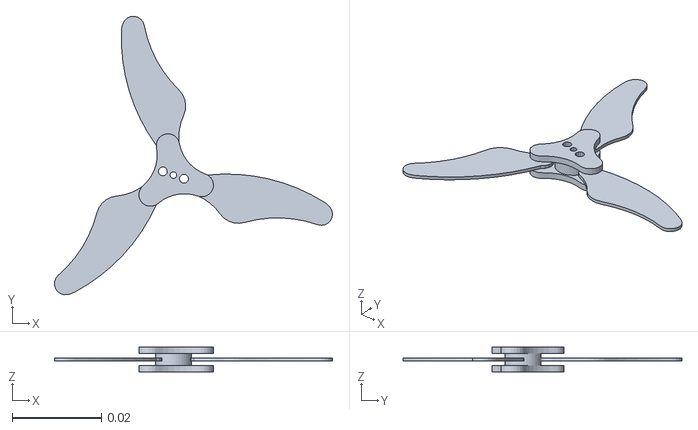
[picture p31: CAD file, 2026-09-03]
无人机/四轴无人机/程序源码/MATLAB程序/SIMSCAPE/meshes/Rotor4.STL
0.0622 x 0.0623 x 0.0055

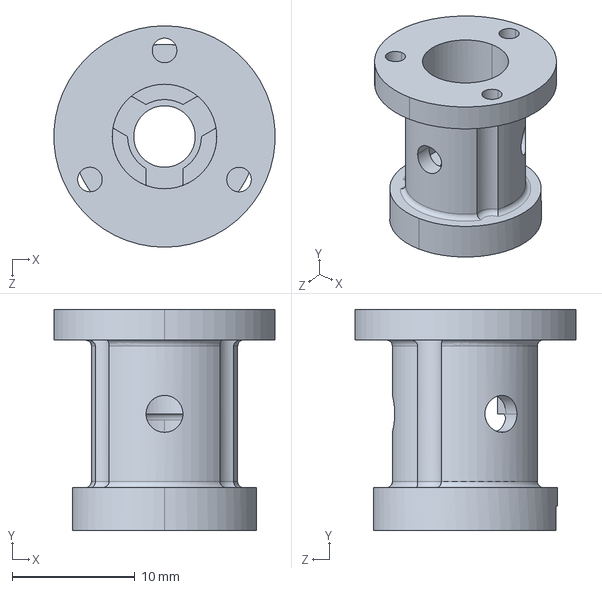
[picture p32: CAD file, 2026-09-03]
无人机/初学者复刻/模型(电机底座＋调试架)/电机支座(需4个).STEP
18.0 x 18.0 x 18.0 mm

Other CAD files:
无人机/四轴无人机/程序源码/MATLAB程序/SIMSCAPE/meshes/Rotor3.STL
无人机/四轴无人机/程序源码/MATLAB程序/SIMSCAPE/meshes/Rotor2.STL

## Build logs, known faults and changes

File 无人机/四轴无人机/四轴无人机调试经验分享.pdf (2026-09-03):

# 1. PID 调参方法分享

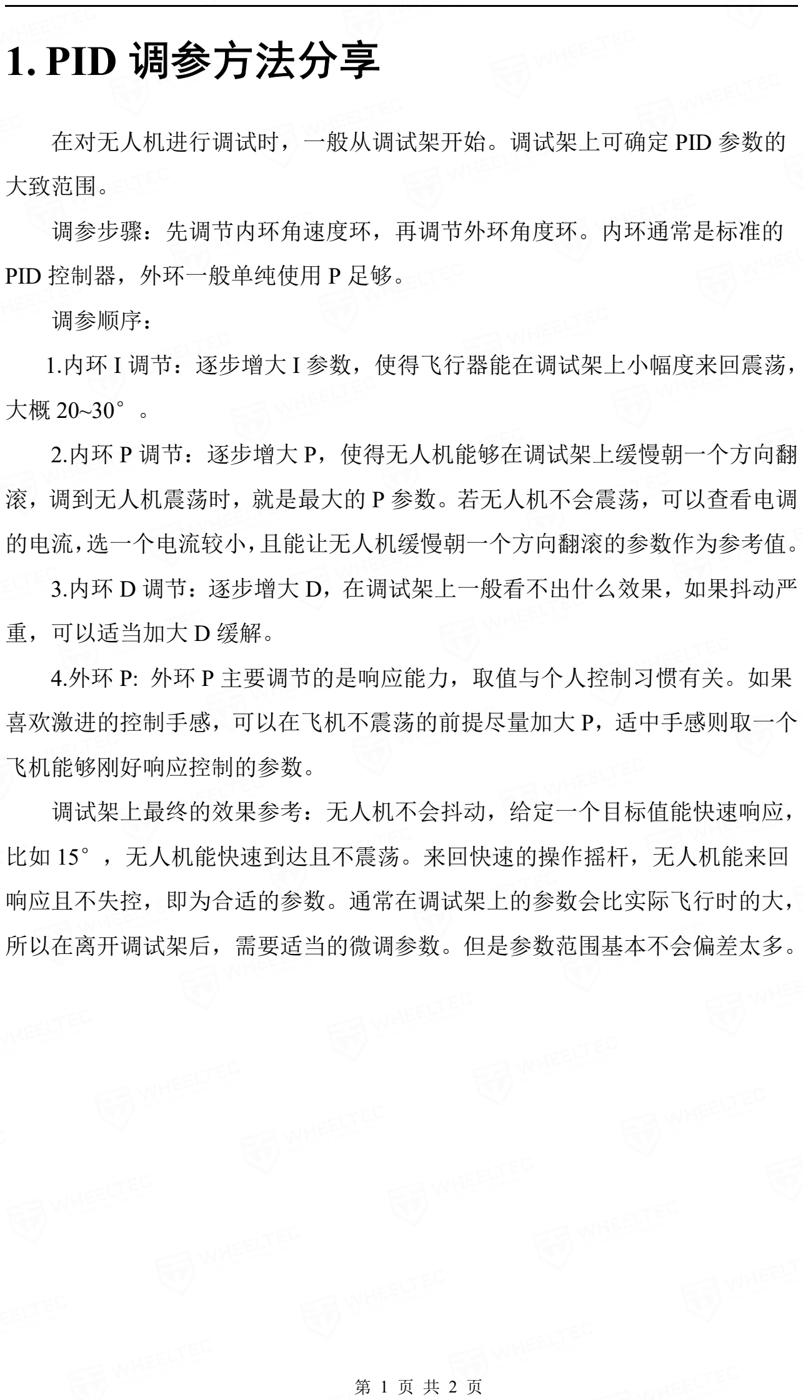
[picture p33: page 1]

第 1 页 共 2 页

在对无人机进行调试时，一般从调试架开始。调试架上可确定 PID 参数的

大致范围。

调参步骤：先调节内环角速度环，再调节外环角度环。内环通常是标准的

PID 控制器，外环一般单纯使用 P 足够。

调参顺序：

1.内环 I 调节：逐步增大 I 参数，使得飞行器能在调试架上小幅度来回震荡，
大概 20~30°。

2.内环 P 调节：逐步增大 P，使得无人机能够在调试架上缓慢朝一个方向翻

滚，调到无人机震荡时，就是最大的 P 参数。若无人机不会震荡，可以查看电调

的电流，选一个电流较小，且能让无人机缓慢朝一个方向翻滚的参数作为参考值。

3.内环 D 调节：逐步增大 D，在调试架上一般看不出什么效果，如果抖动严

重，可以适当加大 D 缓解。

4.外环 P: 外环 P 主要调节的是响应能力，取值与个人控制习惯有关。如果

喜欢激进的控制手感，可以在飞机不震荡的前提尽量加大 P，适中手感则取一个

飞机能够刚好响应控制的参数。

调试架上最终的效果参考：无人机不会抖动，给定一个目标值能快速响应，

比如 15°，无人机能快速到达且不震荡。来回快速的操作摇杆，无人机能来回

响应且不失控，即为合适的参数。通常在调试架上的参数会比实际飞行时的大，

所以在离开调试架后，需要适当的微调参数。但是参数范围基本不会偏差太多。

# 2. 疑难杂症解决分享

## 2.1IMU 问题：

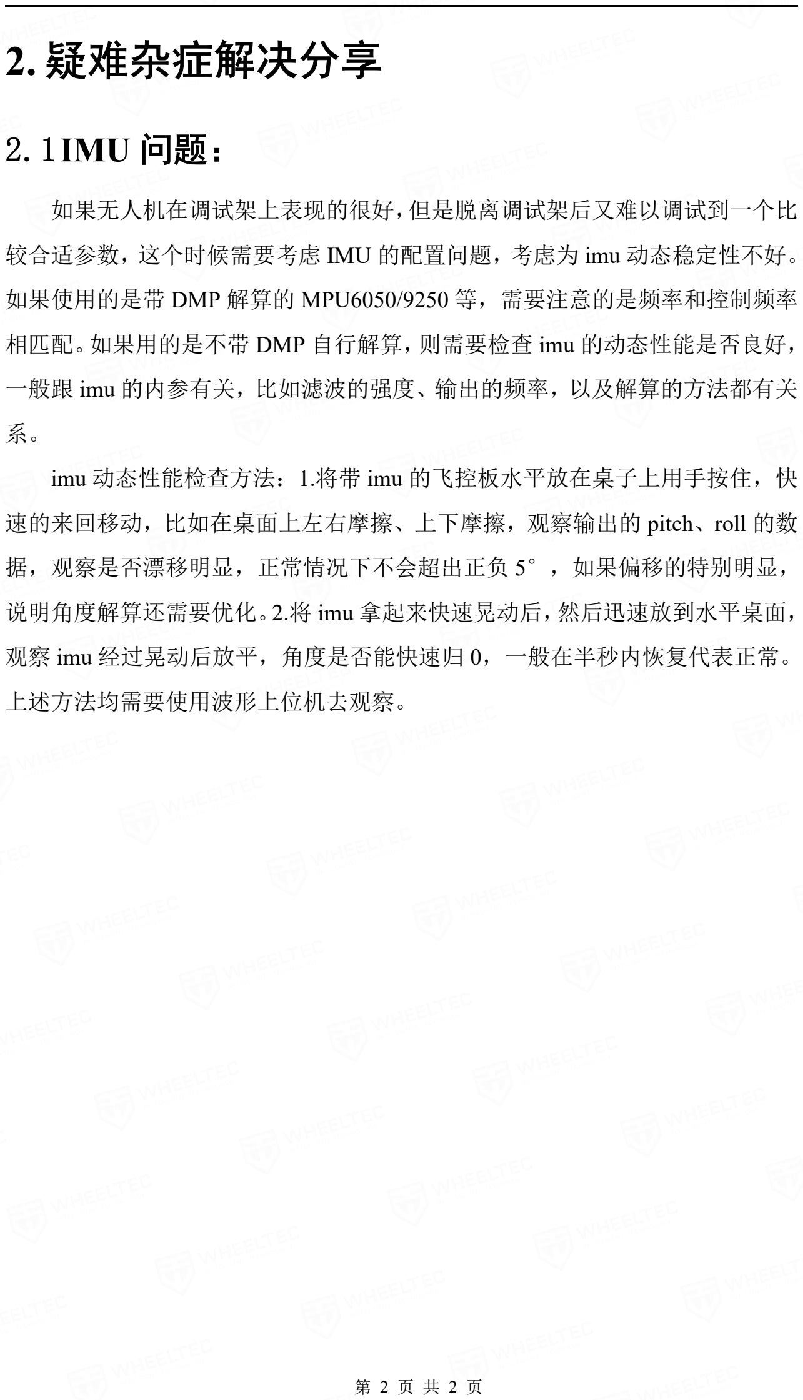
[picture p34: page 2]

第 2 页 共 2 页

如果无人机在调试架上表现的很好，但是脱离调试架后又难以调试到一个比

较合适参数，这个时候需要考虑 IMU 的配置问题，考虑为 imu 动态稳定性不好。

如果使用的是带 DMP 解算的 MPU6050/9250 等，需要注意的是频率和控制频率

相匹配。如果用的是不带 DMP 自行解算，则需要检查 imu 的动态性能是否良好，

一般跟 imu 的内参有关，比如滤波的强度、输出的频率，以及解算的方法都有关

系。

imu 动态性能检查方法：1.将带 imu 的飞控板水平放在桌子上用手按住，快

速的来回移动，比如在桌面上左右摩擦、上下摩擦，观察输出的 pitch、roll 的数

据，观察是否漂移明显，正常情况下不会超出正负 5°，如果偏移的特别明显，

说明角度解算还需要优化。2.将 imu 拿起来快速晃动后，然后迅速放到水平桌面，

观察 imu 经过晃动后放平，角度是否能快速归 0，一般在半秒内恢复代表正常。

上述方法均需要使用波形上位机去观察。

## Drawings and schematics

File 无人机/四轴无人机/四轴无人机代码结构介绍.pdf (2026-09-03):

# 文件夹功能说明

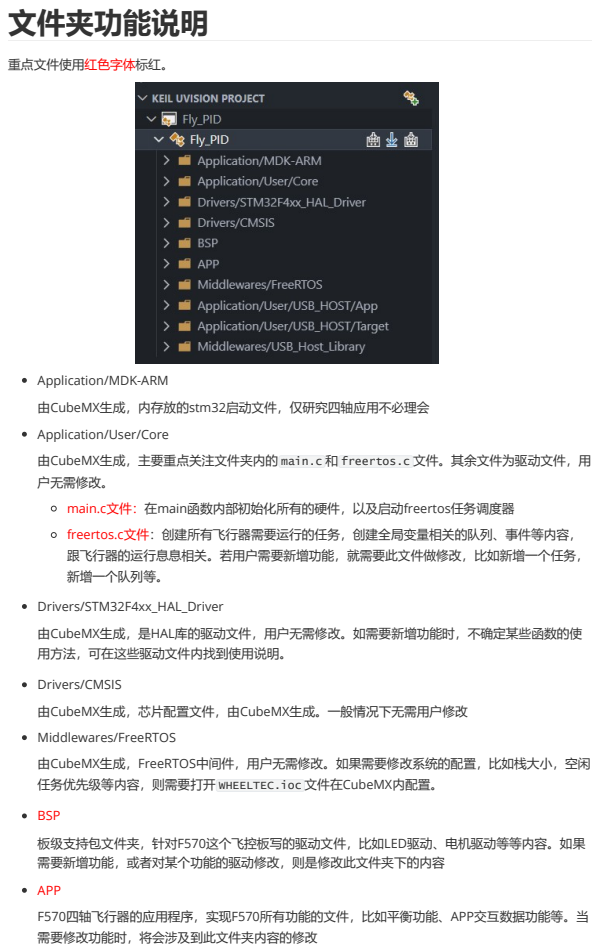
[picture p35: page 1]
重点文件使用红色字体标红。

Application/MDK-ARM
由CubeMX生成，内存放的stm32启动文件，仅研究四轴应用不必理会
Application/User/Core
由CubeMX生成，主要重点关注文件夹内的 main.c 和 freertos.c 文件。其余文件为驱动文件，用
户无需修改。
main.c文件：在main函数内部初始化所有的硬件，以及启动freertos任务调度器
freertos.c文件：创建所有飞行器需要运行的任务，创建全局变量相关的队列、事件等内容，
跟飞行器的运行息息相关。若用户需要新增功能，就需要此文件做修改，比如新增一个任务，
新增一个队列等。
Drivers/STM32F4xx_HAL_Driver
由CubeMX生成，是HAL库的驱动文件，用户无需修改。如需要新增功能时，不确定某些函数的使
用方法，可在这些驱动文件内找到使用说明。
Drivers/CMSIS
由CubeMX生成，芯片配置文件，由CubeMX生成。一般情况下无需用户修改
Middlewares/FreeRTOS
由CubeMX生成，FreeRTOS中间件，用户无需修改。如果需要修改系统的配置，比如栈大小，空闲
任务优先级等内容，则需要打开 WHEELTEC.ioc 文件在CubeMX内配置。
BSP
板级支持包文件夹，针对F570这个飞控板写的驱动文件，比如LED驱动、电机驱动等等内容。如果
需要新增功能，或者对某个功能的驱动修改，则是修改此文件夹下的内容
APP
F570四轴飞行器的应用程序，实现F570所有功能的文件，比如平衡功能、APP交互数据功能等。当
需要修改功能时，将会涉及到此文件夹内容的修改

# 重点文件说明

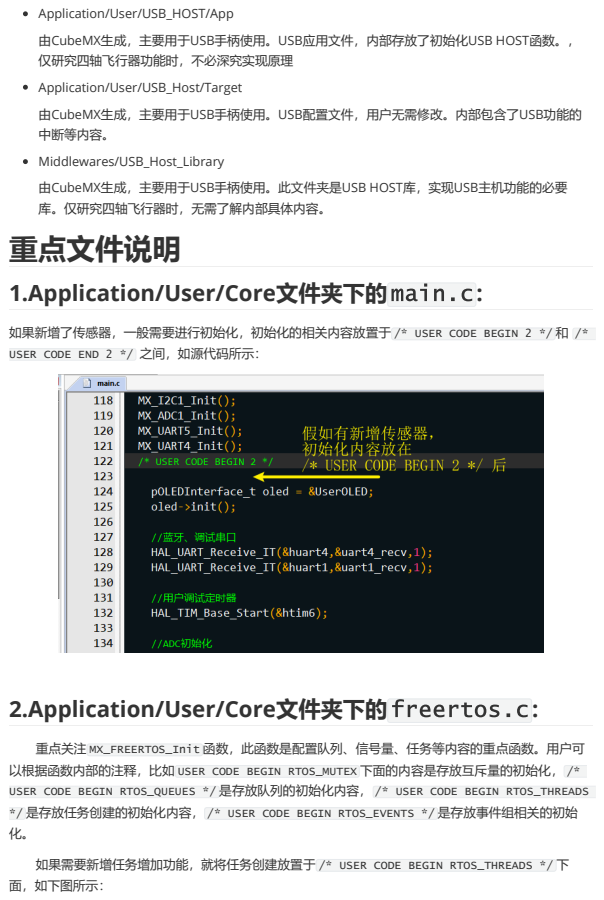
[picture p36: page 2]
如果新增了传感器，一般需要进行初始化，初始化的相关内容放置于 /* USER CODE BEGIN 2 */ 和; USER CODE END 2 */; 之间，如源代码所示：

Application/User/USB_HOST/App
由CubeMX生成，主要用于USB手柄使用。USB应用文件，内部存放了初始化USB HOST函数。，
仅研究四轴飞行器功能时，不必深究实现原理
Application/User/USB_Host/Target
由CubeMX生成，主要用于USB手柄使用。USB配置文件，用户无需修改。内部包含了USB功能的
中断等内容。
Middlewares/USB_Host_Library
由CubeMX生成，主要用于USB手柄使用。此文件夹是USB HOST库，实现USB主机功能的必要
库。仅研究四轴飞行器时，无需了解内部具体内容。

1.Application/User/Core文件夹下的main.c :

2.Application/User/Core文件夹下的freertos.c :

重点关注 MX_FREERTOS_Init 函数，此函数是配置队列、信号量、任务等内容的重点函数。用户可
以根据函数内部的注释，比如 USER CODE BEGIN RTOS_MUTEX 下面的内容是存放互斥量的初始化， /*
USER CODE BEGIN RTOS_QUEUES */ 是存放队列的初始化内容， /* USER CODE BEGIN RTOS_THREADS
*/ 是存放任务创建的初始化内容， /* USER CODE BEGIN RTOS_EVENTS */ 是存放事件组相关的初始

如果需要新增任务增加功能，就将任务创建放置于 /* USER CODE BEGIN RTOS_THREADS */ 下
面，如下图所示：

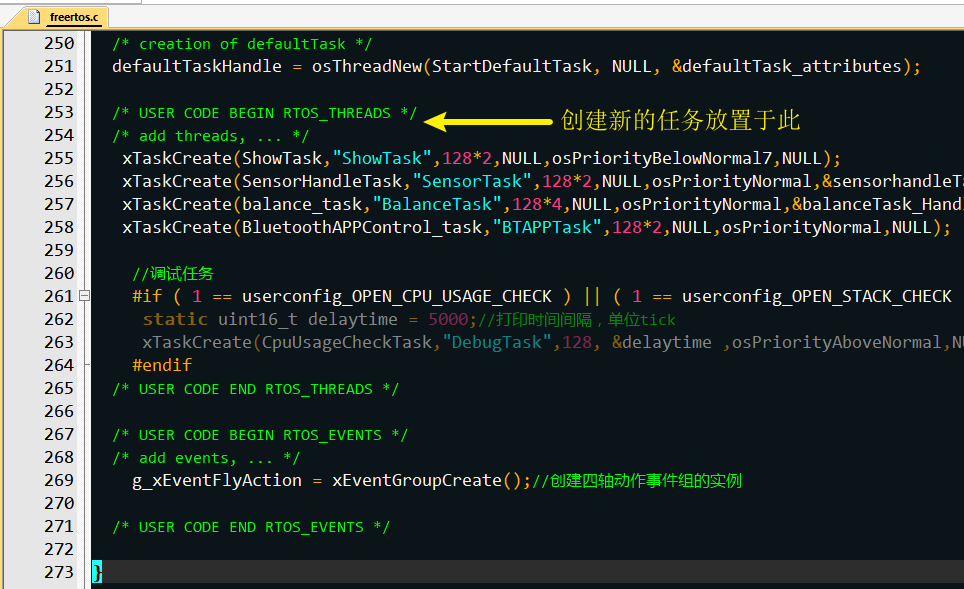
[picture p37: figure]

常规的驱动文件可以自行打开浏览理解，这里不作一一解释，主要对特殊功能做一些解释。

bsp_RTOSdebug.c 驱动文件
这个驱动可以对FreeRTOS的任务进行监测，非RTOS任务也可以，比如中断环境。可以测量某 个操作的用时，也可以测量某个任务执行的频率。注意测量是毫秒级别的，太快的操作无法捕获， 定时器的频率的在10000Hz，高于这个频率的操作无法捕获。这个功能可以用来检测任务的频率是

# BSP文件夹

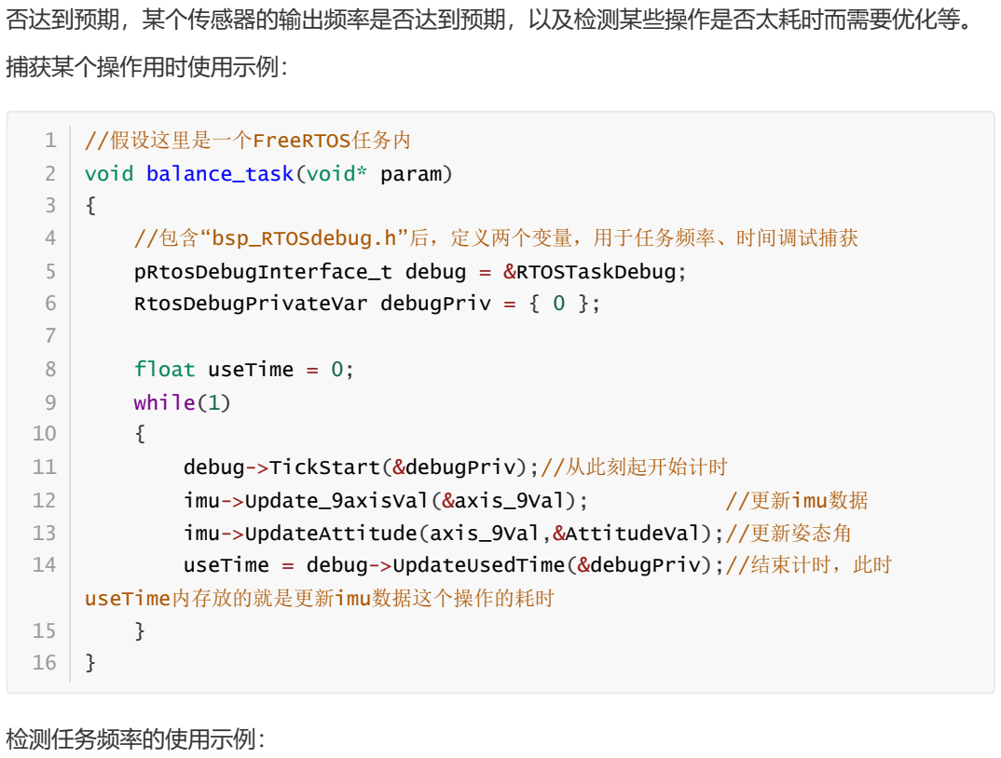
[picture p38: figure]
否达到预期，某个传感器的输出频率是否达到预期，以及检测某些操作是否太耗时而需要优化等。; 捕获某个操作用时使用示例：; 检测任务频率的使用示例：; //假设这里是一个FreeRTOS任务内; void balance_task(void* param); //包含“bsp_RTOSdebug.h”后，定义两个变量，用于任务频率、时间调试捕获; pRtosDebugInterface_t debug = &RTOSTaskDebug;; RtosDebugPrivateVar debugPriv = { 0 };; float useTime = 0;; while(1); debug->TickStart(&debugPriv);//从此刻起开始计时; imu->Update_9axisVal(&axis_9Val);; //更新imu数据; imu->UpdateAttitude(axis_9Val,&AttitudeVal);//更新姿态角; useTime = debug->UpdateUsedTime(&debugPriv);//结束计时，此时; useTime内存放的就是更新imu数据这个操作的耗时
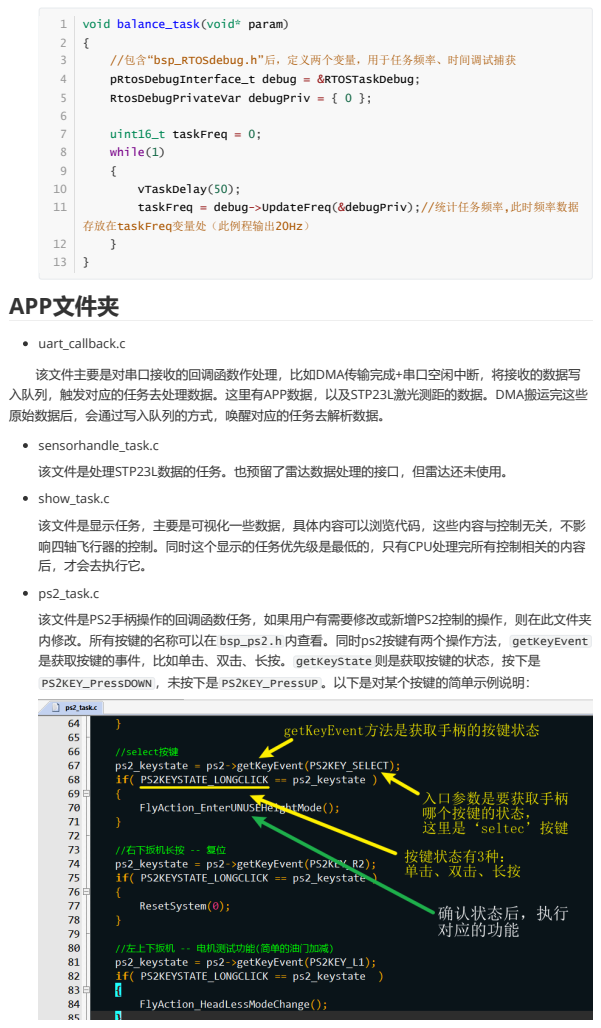
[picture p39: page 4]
存放在taskFreq变量处（此例程输出20Hz）; 13 APP文件夹

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

uint16_t taskFreq = 0;
while(1)
vTaskDelay(50);
taskFreq = debug->UpdateFreq(&debugPriv);//统计任务频率,此时频率数据

uart_callback.c
该文件主要是对串口接收的回调函数作处理，比如DMA传输完成+串口空闲中断，将接收的数据写
入队列，触发对应的任务去处理数据。这里有APP数据，以及STP23L激光测距的数据。DMA搬运完这些
原始数据后，会通过写入队列的方式，唤醒对应的任务去解析数据。
sensorhandle_task.c
该文件是处理STP23L数据的任务。也预留了雷达数据处理的接口，但雷达还未使用。
show_task.c
该文件是显示任务，主要是可视化一些数据，具体内容可以浏览代码，这些内容与控制无关，不影
响四轴飞行器的控制。同时这个显示的任务优先级是最低的，只有CPU处理完所有控制相关的内容
后，才会去执行它。
ps2_task.c
该文件是PS2手柄操作的回调函数任务，如果用户有需要修改或新增PS2控制的操作，则在此文件夹
内修改。所有按键的名称可以在 bsp_ps2.h 内查看。同时ps2按键有两个操作方法， getKeyEvent
是获取按键的事件，比如单击、双击、长按。 getKeyState 则是获取按键的状态，按下是
PS2KEY_PressDOWN ，未按下是 PS2KEY_PressUP 。以下是对某个按键的简单示例说明：

bluetoothControl_task.c
此文件是蓝牙APP的相关内容，可以对APP的操作进行解析。

balance_task.c
此文件是四轴飞行器的主要逻辑任务，平衡功能由此任务完成，内含平衡的算法，传感器数据的使 用等。如果需要研究飞行器的稳态以及算法内容，则需要仔细阅读浏览此文件学习。 pid.c
PID算法版本才有的文件，内含PID算法，以及PID控制的定义。如需要修改PID参数，可以在此文件 内进行修改。如下图示：

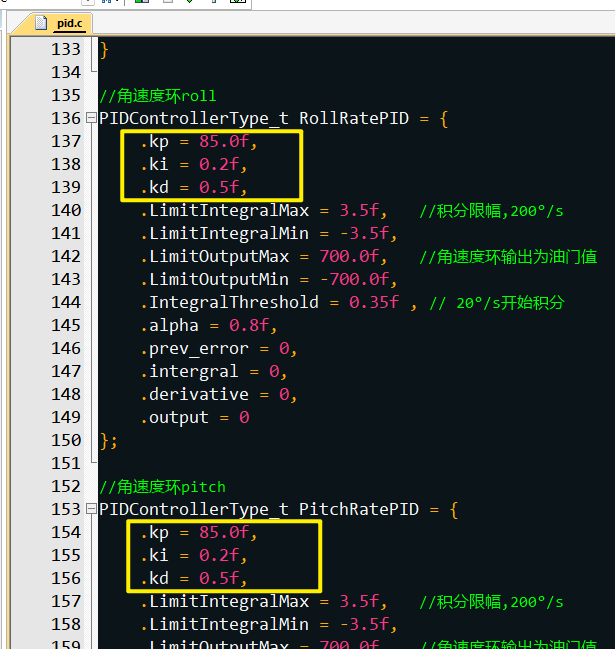
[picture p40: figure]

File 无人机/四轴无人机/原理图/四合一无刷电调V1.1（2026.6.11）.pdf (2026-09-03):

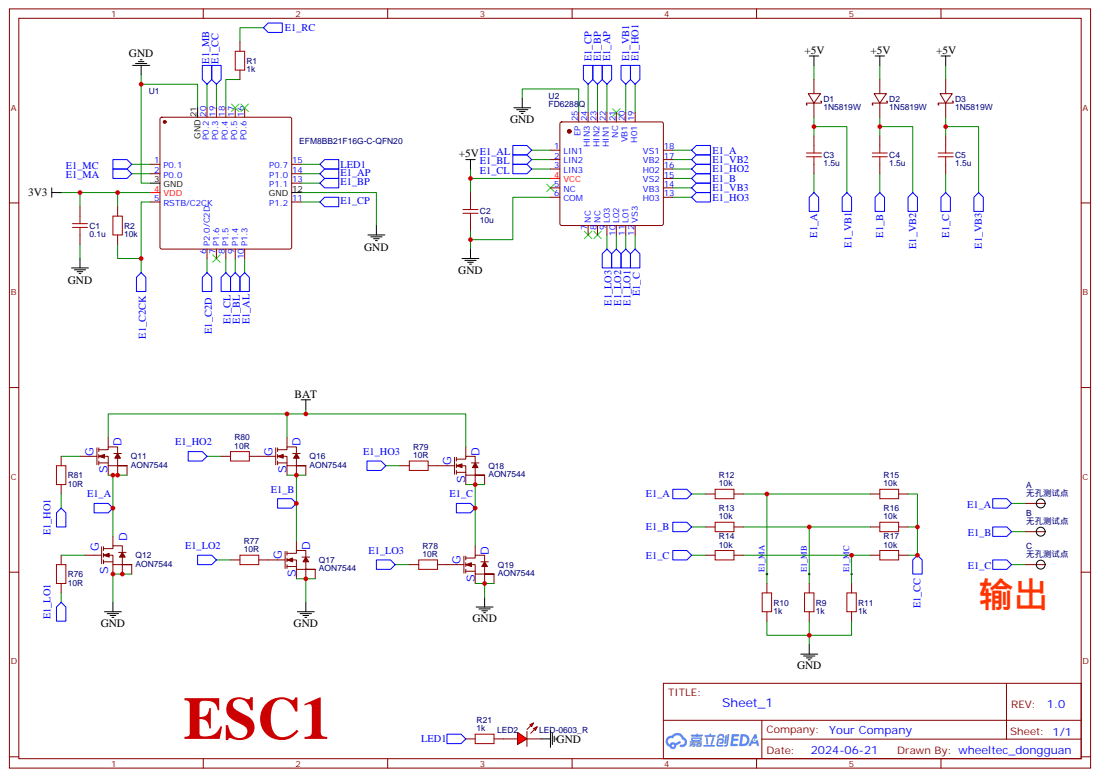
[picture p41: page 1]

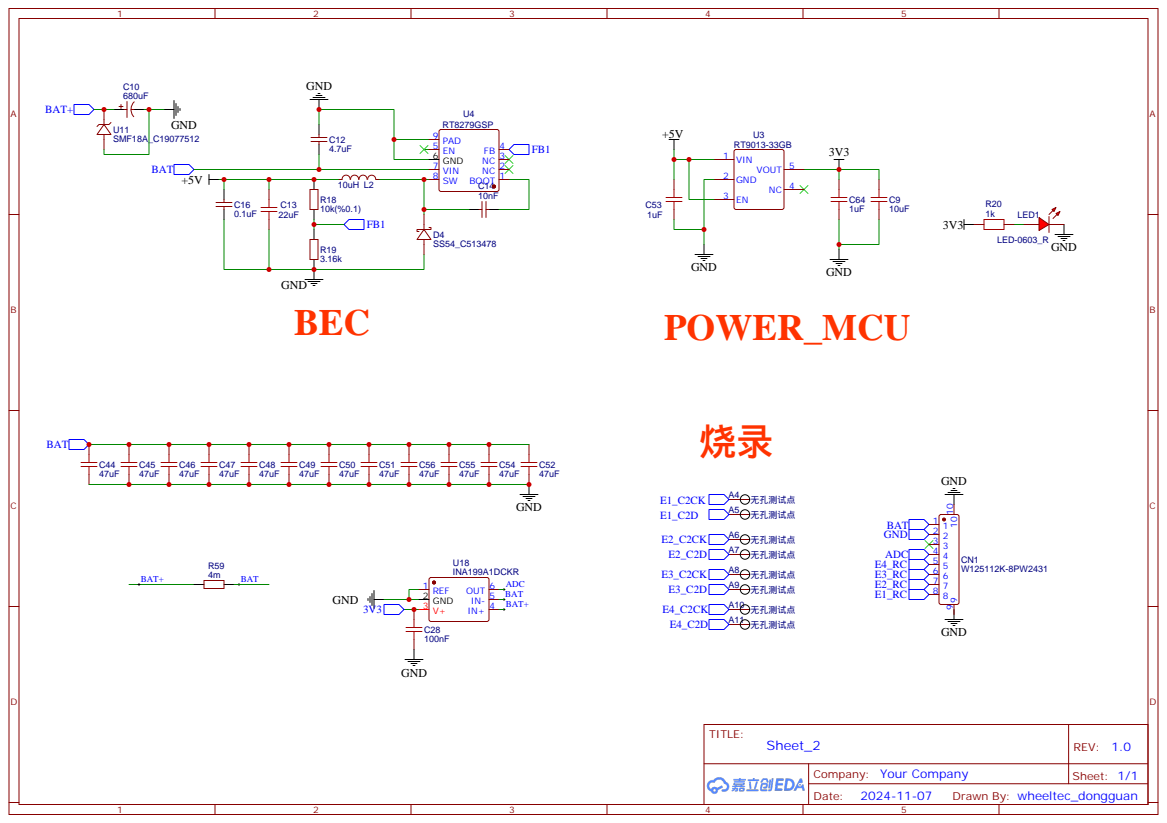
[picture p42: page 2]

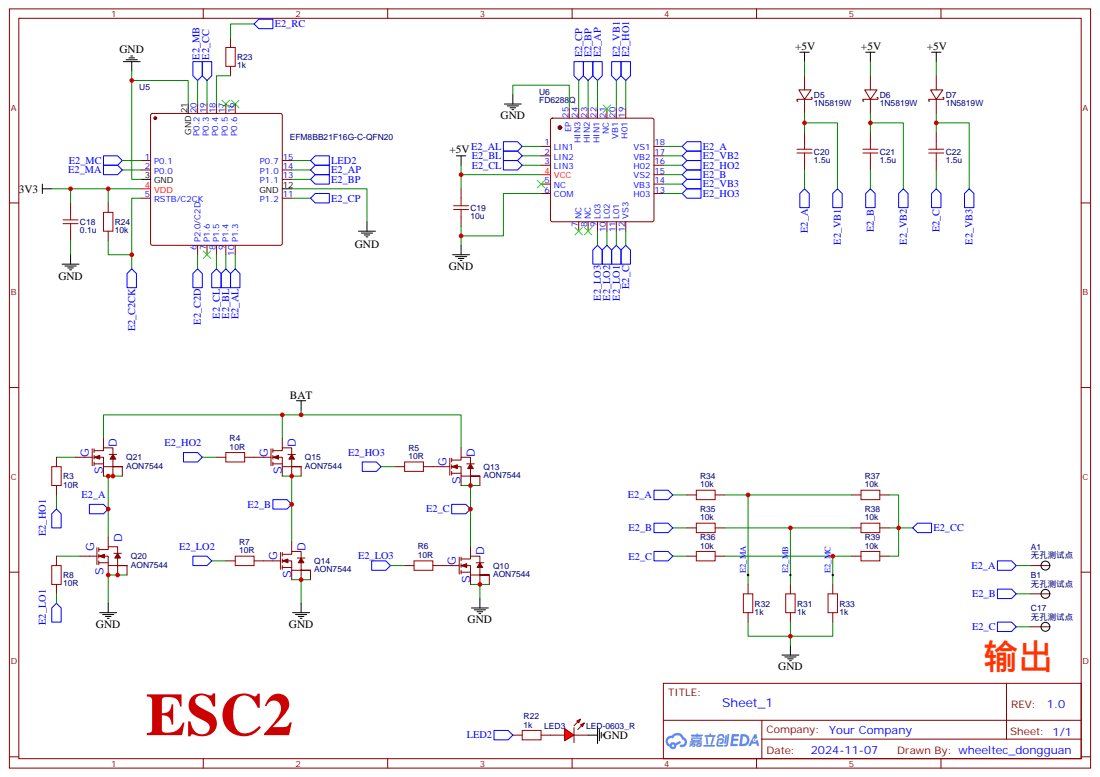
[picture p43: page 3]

Company: Your Company GND

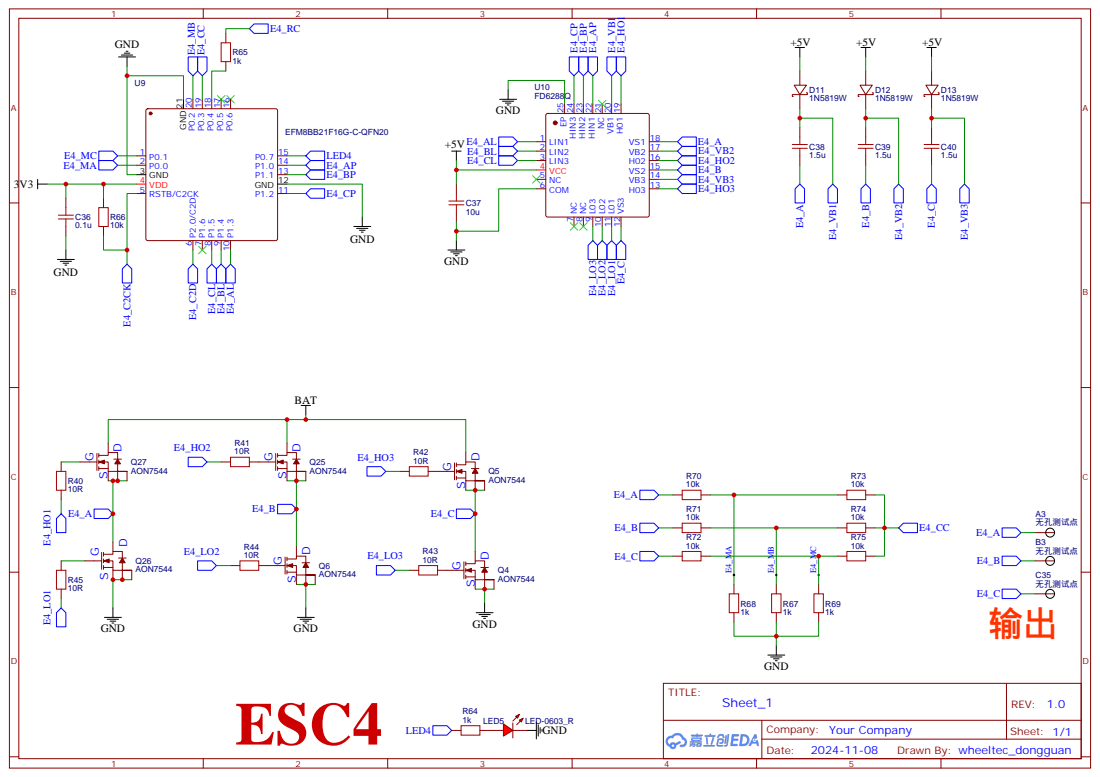
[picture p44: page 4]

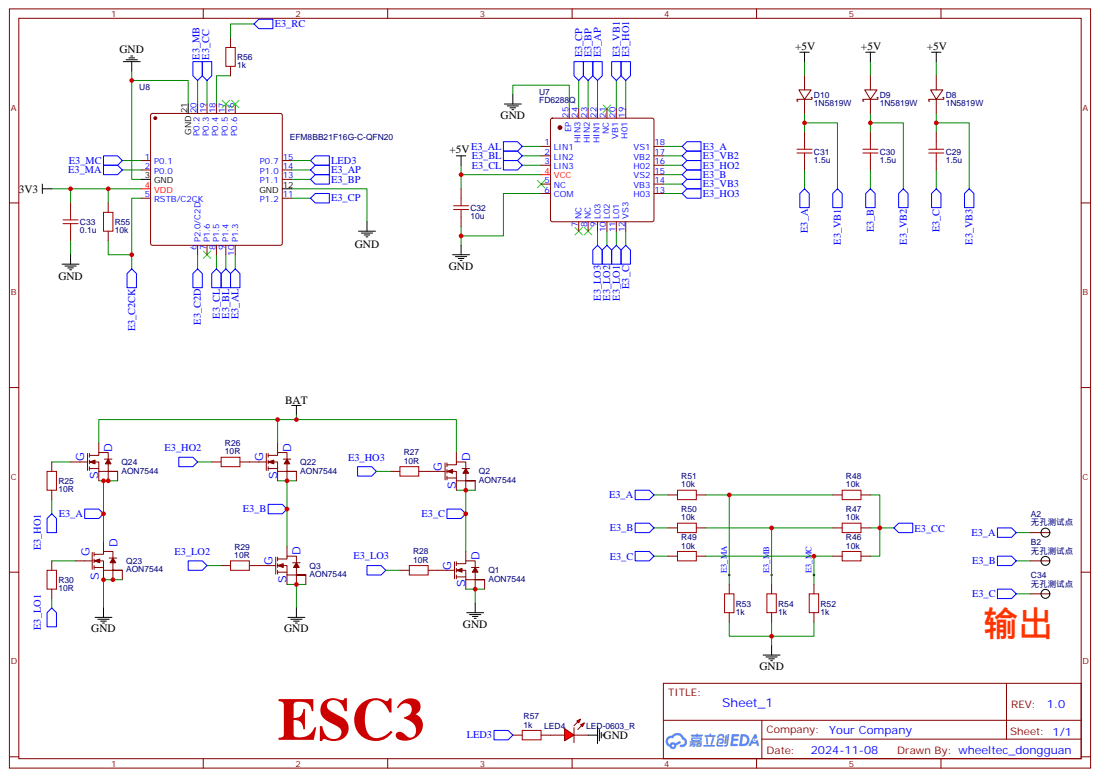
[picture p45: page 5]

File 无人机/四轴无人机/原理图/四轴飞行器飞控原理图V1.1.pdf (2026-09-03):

## 复位按键

# UART5-STP23L

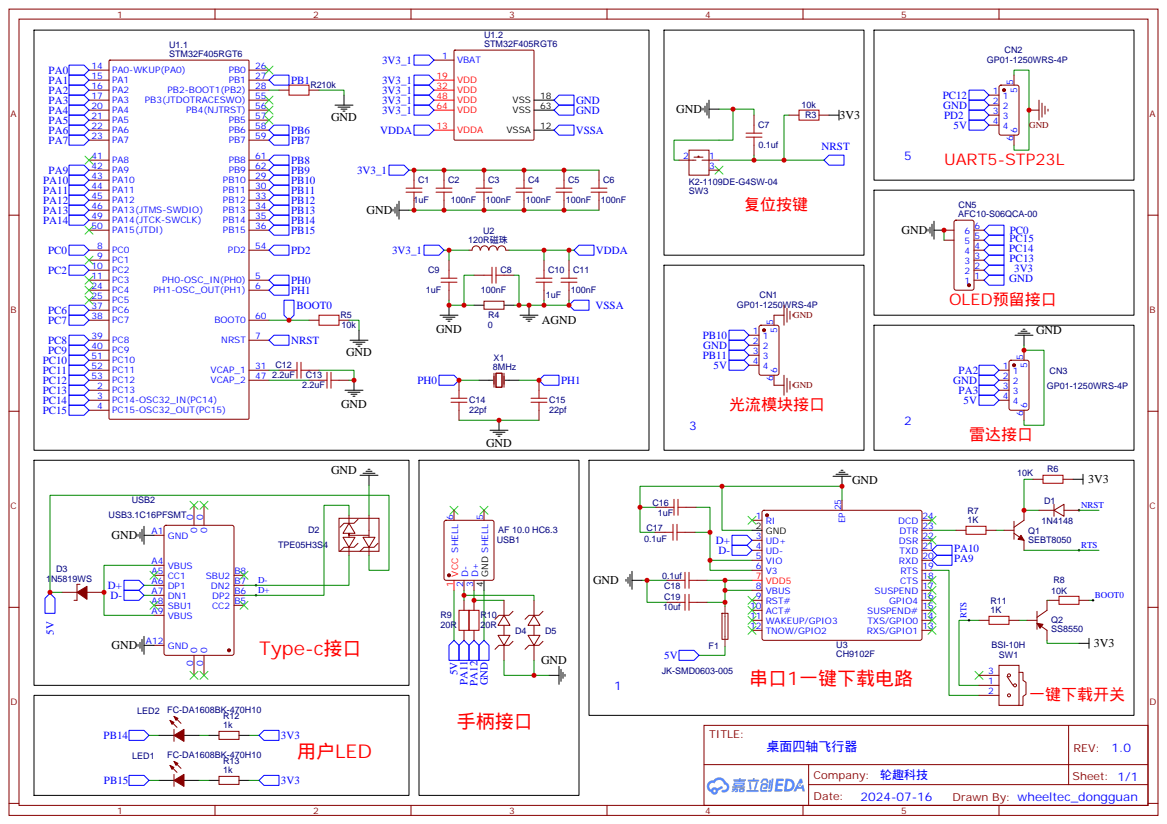
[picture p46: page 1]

手柄接口 PA¹¹ PA¹² GND

# 板载过温保护 SMBJ3.3A D⁷


VDD 13 NC 14 NC 15 NC 16 NC 17 GND 18



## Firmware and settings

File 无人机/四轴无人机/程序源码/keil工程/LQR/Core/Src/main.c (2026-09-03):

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
/* Includes ------------------------------------------------------------------*/
#include "main.h"
#include "cmsis_os.h"
#include "adc.h"
#include "dma.h"
#include "i2c.h"
#include "tim.h"
#include "usart.h"
#include "usb_host.h"
#include "gpio.h"

/* USER CODE BEGIN Includes */
/* C 标准库 ------------------------------------------------------------------*/
#include <stdio.h>              /* 标准输入输出，提供 printf/scanf 重定向支持 */

/* FreeRTOS ------------------------------------------------------------------*/
#include "FreeRTOS.h"           /* FreeRTOS 内核接口 */
#include "semphr.h"             /* 信号量/互斥锁接口 */

/* HAL 库 --------------------------------------------------------------------*/
/* （HAL 外设头文件已在 main.h 中通过 stm32f4xx_hal.h 统一引入） */

/* BSP 板级支持包 -------------------------------------------------------------*/
#include "bsp_led.h"            /* LED 指示灯驱动 */
#include "bsp_oled.h"           /* OLED 显示屏驱动 */
#include "bsp_adc.h"            /* ADC 采样驱动（电池电压/电流检测） */
#include "bsp_imu.h"            /* IMU 惯性测量单元驱动（ICM20948） */
#include "bsp_LC307.h"          /* LC307 激光测距模块驱动 */
/* USER CODE END Includes */


/* USER CODE BEGIN PV */
/* 串口中断接收缓存 -----------------------------------------------------------*/
uint8_t uart1_recv;             /* USART1 单字节中断接收缓存（蓝牙模块） */
uint8_t uart4_recv;             /* UART4  单字节中断接收缓存（调试串口） */

/* 用户校准参数 ---------------------------------------------------------------*/
float g_userparam_pitchzero = 0; /* 用户设定的俯仰角零点偏移（从 Flash 读取） */
float g_userparam_rollzero  = 0; /* 用户设定的横滚角零点偏移（从 Flash 读取） */

/* 调试数据显示结构体 ---------------------------------------------------------*/
DebugShowVal_t g_debugVal = { 0 }; /* 调试用全局变量，可通过串口/OLED 查看各传感器数据 */
/* USER CODE END PV */

void SystemClock_Config(void);
void MX_FREERTOS_Init(void);
/**
  * @brief  The application entry point.
  * @retval int
  */
int main(void)
{

  /* MCU Configuration--------------------------------------------------------*/

  /* Reset of all peripherals, Initializes the Flash interface and the Systick. */
  HAL_Init();

  /* Configure the system clock */
  SystemClock_Config();

  /* Initialize all configured peripherals */
  MX_GPIO_Init();
  MX_DMA_Init();
  MX_USART1_UART_Init();
  MX_USART2_UART_Init();
  MX_TIM6_Init();
  MX_TIM8_Init();
  MX_I2C1_Init();
  MX_ADC1_Init();
  MX_UART5_Init();
  MX_UART4_Init();
  MX_USART3_UART_Init();
  /* USER CODE BEGIN 2 */

	/* OLED 显示屏初始化 ----------------------------------------------------*/
	/* 使用 I2C1 接口驱动 OLED 显示模块 */
	pOLEDInterface_t oled = &UserOLED;
	oled->init();

	/* 启动串口中断接收 ------------------------------------------------------*/
	/* UART4: 调试串口（printf 重定向），UART1: 蓝牙模块，均使能单字节中断接收 */
	HAL_UART_Receive_IT(&huart4, &uart4_recv, 1);
	HAL_UART_Receive_IT(&huart1, &uart1_recv, 1);

	/* 启动用户基础定时器 ----------------------------------------------------*/
	/* TIM6 用作系统时基或周期任务调度时钟源 */
	HAL_TIM_Base_Start(&htim6);

	/* ADC 初始化 ------------------------------------------------------------*/
	/* ADC1 用于采集电池电压 (Battery_Ch) 和电流检测通道 (cur_ch) */
	pADCInterface_t adc1 = &UserADC1;
	adc1->init();

	/* 硬件 I2C 总线忙异常恢复处理 -------------------------------------------*/
	/* 上电或异常复位后，I2C 从设备可能将 SDA 拉低导致 BUSY 标志置位 */
	/* 此处检测并强制释放 I2C 总线，然后重新初始化外设 */
	if ((I2C1->SR2 >> 1) & 0x01)       /* 检查 I2C1 SR2 寄存器的 BUSY 标志位 */
	{
		HAL_I2C_MspDeInit(&hi2c1);      /* 反初始化 I2C MSP（释放引脚复用回 GPIO） */

		/* 将 I2C 引脚 (PB6=SCL, PB7=SDA) 配置为 GPIO 推挽输出，模拟时钟释放总线 */
		GPIO_InitTypeDef GPIO_InitStruct = {0};
		GPIO_InitStruct.Pin   = GPIO_PIN_6 | GPIO_PIN_7;
		GPIO_InitStruct.Mode  = GPIO_MODE_OUTPUT_PP;
		GPIO_InitStruct.Pull  = GPIO_PULLUP;
		GPIO_InitStruct.Speed = GPIO_SPEED_FREQ_LOW;
		HAL_GPIO_Init(GPIOB, &GPIO_InitStruct);
		HAL_GPIO_WritePin(GPIOB, GPIO_PIN_6, GPIO_PIN_SET); /* SCL 拉高 */
		HAL_GPIO_WritePin(GPIOB, GPIO_PIN_7, GPIO_PIN_SET); /* SDA 拉高 */

		/* 重新初始化 I2C1 外设，清除 BUSY 状态 */
		I2C1->CR1 &= ~(1 << 0);         /* PE=0: 关闭 I2C 使能 */
		HAL_Delay(50);                  /* 等待总线稳定 */
		I2C1->CR1 |= (1 << 0);          /* PE=1: 重新使能 I2C */
		I2C1->CR1 |= (1 << 15);         /* SWRST=1: 软件复位 I2C */
		HAL_Delay(50);
		I2C1->CR1 &= ~(1 << 15);        /* 清除复位位 */
		MX_I2C1_Init();                 /* 重新调用 CubeMX 生成的 I2C 初始化函数 */
	}

	/* ICM20948 IMU 初始化与状态指示 -----------------------------------------*/
	/* 使用 User_LED1 指示 IMU 初始化状态：闪烁=正在初始化，常亮=初始化成功 */
	pLedInterface_t  imu_initled = &UserLed1;
	pIMUInterface_t  imu         = &UserICM20948;

	imu_initled->off();
	while (imu->Init())                   /* 循环初始化 IMU 直到成功 */
	{
		imu_initled->toggle();            /* LED 闪烁表示初始化过程持续中 */
		HAL_Delay(60);
		NVIC_SystemReset();               /* 初始化超时则执行系统复位重试 */
	}
	imu_initled->on();                    /* LED 常亮指示 IMU 初始化成功完成 */

	/* 激光测距模块初始化 ----------------------------------------------------*/
	/* LC307 / STP23L 激光测距模块，用于对地高度测量 */
	Opf_LC307_Init();

	/* 从 Flash 读取用户校准参数 ---------------------------------------------*/
	/* 读取存储的俯仰角和横滚角零点偏移值（出厂校准或用户设定值） */
	extern void User_Flash_ReadParam(uint32_t* p, uint16_t datalen);
	int32_t tmp[2] = { 0 };
	User_Flash_ReadParam((uint32_t*)tmp, 2);
	if (tmp[0] != 0xffffffff)             /* 0xFFFFFFFF 表示 Flash 该地址未被写入过（擦除态） */
		g_userparam_pitchzero = *((float*)&tmp[0]);
	if (tmp[1] != 0xffffffff)
		g_userparam_rollzero  = *((float*)&tmp[1]);

  /* USER CODE END 2 */

  /* Init scheduler */
  osKernelInitialize();

  /* Call init function for freertos objects (in cmsis_os2.c) */
  MX_FREERTOS_Init();

  /* Start scheduler */
  osKernelStart();

  /* We should never get here as control is now taken by the scheduler */

  /* Infinite loop */
  /* USER CODE BEGIN WHILE */
  while (1)
  {
    /* USER CODE END WHILE */

    /* USER CODE BEGIN 3 */
    /* FreeRTOS 任务调度运行中，此循环体由 osKernelStart() 内部的调度器控制 */
    /* 用户任务代码在各 APP 任务文件中实现（balance_task, lidar_task 等） */
  }
  /* USER CODE END 3 */
}

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
/* USER CODE BEGIN 4 */

/* 调试串口句柄 ---------------------------------------------------------------*/
/* 将 huart4 重命名为 DebugSerial，用于 printf/scanf 重定向 */
UART_HandleTypeDef *DebugSerial = &huart4;

/**
  * @brief  printf 重定向底层函数：将字符通过串口发送
  * @param  ch:     要发送的字符
  * @param  stream: 文件流指针（未使用）
  * @retval 发送的字符
  * @note   重写 C 库的 fputc 实现 printf 串口输出
  */
int fputc(int ch, FILE* stream)
{
	while (HAL_OK != HAL_UART_Transmit(DebugSerial, (const uint8_t *)&ch, 1, 100));
	return ch;
}

/* scanf 重定向所需的互斥锁和状态变量 -----------------------------------------*/
static xSemaphoreHandle debug_1_HandleMutex;  /* 保护 scanf 回退缓冲区的互斥锁 */
static char g_last_char;                       /* 上次接收的字符（用于 backspace 回退） */
static char g_backspace;                       /* backspace 回退标志（非零表示下次读取返回缓存字符） */

/**
  * @brief  scanf 重定向底层函数：从串口接收字符
  * @param  f: 文件流指针（未使用）
  * @retval 接收到的字符
  * @note   重写 C 库的 fgetc 实现 scanf 串口输入，支持 backspace 功能
  */
int fgetc(FILE* f)
{
	/* 首次调用时创建互斥锁（延迟初始化） */
	static uint8_t init = 0;
	if (init == 0)
	{
		init = 1;
		debug_1_HandleMutex = xSemaphoreCreateMutex();
	}

	int ch;
	if (g_backspace)
	{
		/* 处理 backspace：返回上次缓存的字符而不是从串口读取 */
		xSemaphoreTake(debug_1_HandleMutex, portMAX_DELAY);
		g_backspace = 0;
		xSemaphoreGive(debug_1_HandleMutex);

		return g_last_char;
	}

	/* 阻塞等待串口接收一个字符 */
	while (HAL_OK != HAL_UART_Receive(DebugSerial, (uint8_t *)&ch, 1, HAL_MAX_DELAY));
	g_last_char = ch;
	return ch;
}

/**
  * @brief  scanf backspace 支持函数：将上次读取的字符回退到输入流
  * @param  stream: 文件流指针（未使用）
  * @retval 0
  * @note   配合 fgetc 实现 scanf 的退格编辑功能
  */
int __backspace(FILE *stream)
{
	xSemaphoreTake(debug_1_HandleMutex, portMAX_DELAY);
	g_backspace = 1;
	xSemaphoreGive(debug_1_HandleMutex);
	return 0;
}

/**
  * @brief  TIM8 定时器更新中断回调函数（弱定义）
  * @note   用户可重写此函数实现 TIM8 周期中断自定义处理
  *         当前由 HAL_TIM_PeriodElapsedCallback 中调用
  */
__weak void User_TIM8_UpdateCallback(void)
{
	/* 用户在此添加 TIM8 中断处理代码 */
}

/* USER CODE END 4 */

/**
  * @brief  Period elapsed callback in non blocking mode
  * @note   This function is called  when TIM7 interrupt took place, inside
  * HAL_TIM_IRQHandler(). It makes a direct call to HAL_IncTick() to increment
  * a global variable "uwTick" used as application time base.
  * @param  htim : TIM handle
  * @retval None
  */
void HAL_TIM_PeriodElapsedCallback(TIM_HandleTypeDef *htim)
{
  if (htim->Instance == TIM7) {
    HAL_IncTick();
  }
  /* USER CODE BEGIN Callback 1 */
	else if (TIM8 == htim->Instance)
	{
		/* TIM8 周期中断：调用用户自定义回调 */
		User_TIM8_UpdateCallback();
	}

  /* USER CODE END Callback 1 */
}

/**
  * @brief  This function is executed in case of error occurrence.
  * @retval None
  */
void Error_Handler(void)
{
  /* USER CODE BEGIN Error_Handler_Debug */
  /* User can add his own implementation to report the HAL error return state */
  __disable_irq();
  while (1)
  {
  }
  /* USER CODE END Error_Handler_Debug */
}

#ifdef  USE_FULL_ASSERT
/**
  * @brief  Reports the name of the source file and the source line number
  *         where the assert_param error has occurred.
  * @param  file: pointer to the source file name
  * @param  line: assert_param error line source number
  * @retval None
  */
void assert_failed(uint8_t *file, uint32_t line)
{
  /* USER CODE BEGIN 6 */
  /* User can add his own implementation to report the file name and line number,
     ex: printf("Wrong parameters value: file %s on line %d\r\n", file, line) */
  /* USER CODE END 6 */
}
#endif /* USE_FULL_ASSERT */

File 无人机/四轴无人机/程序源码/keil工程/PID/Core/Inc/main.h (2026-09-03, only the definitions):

#define OLED_SCL_Pin GPIO_PIN_13
#define OLED_SCL_GPIO_Port GPIOC
#define OLED_SDA_Pin GPIO_PIN_14
#define OLED_SDA_GPIO_Port GPIOC
#define OLED_RES_Pin GPIO_PIN_15
#define OLED_RES_GPIO_Port GPIOC
#define OLED_DC_Pin GPIO_PIN_0
#define OLED_DC_GPIO_Port GPIOC
#define Lidar_TX_Pin GPIO_PIN_2
#define Lidar_TX_GPIO_Port GPIOA
#define Lidar_RX_Pin GPIO_PIN_3
#define Lidar_RX_GPIO_Port GPIOA
#define User_BUZZER_Pin GPIO_PIN_4
#define User_BUZZER_GPIO_Port GPIOA
#define Battery_Ch_Pin GPIO_PIN_7
#define Battery_Ch_GPIO_Port GPIOA
#define cur_ch_Pin GPIO_PIN_1
#define cur_ch_GPIO_Port GPIOB
#define IMU_INT_Pin GPIO_PIN_12
#define IMU_INT_GPIO_Port GPIOB
#define IMU_INT_EXTI_IRQn EXTI15_10_IRQn
#define User_KEY_Pin GPIO_PIN_13
#define User_KEY_GPIO_Port GPIOB
#define User_LED1_Pin GPIO_PIN_14
#define User_LED1_GPIO_Port GPIOB
#define User_LED2_Pin GPIO_PIN_15
#define User_LED2_GPIO_Port GPIOB
#define DEBUG_TX_Pin GPIO_PIN_9
#define DEBUG_TX_GPIO_Port GPIOA
#define DEBUG_RX_Pin GPIO_PIN_10
#define DEBUG_RX_GPIO_Port GPIOA
#define BT_TX_Pin GPIO_PIN_10
#define BT_TX_GPIO_Port GPIOC
#define BT_RX_Pin GPIO_PIN_11
#define BT_RX_GPIO_Port GPIOC
#define STP23L_TX_Pin GPIO_PIN_12
#define STP23L_TX_GPIO_Port GPIOC
#define STP23L_RX_Pin GPIO_PIN_2
#define STP23L_RX_GPIO_Port GPIOD
#define sIIC_SCL_Pin GPIO_PIN_10
#define sIIC_SCL_GPIO_Port GPIOB
#define sIIC_SDA_Pin GPIO_PIN_11
#define sIIC_SDA_GPIO_Port GPIOB

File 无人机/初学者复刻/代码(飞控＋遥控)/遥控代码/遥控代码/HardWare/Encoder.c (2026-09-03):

#include "stm32f10x.h"                  // Device header

void Encoder_Init(void)
{
	/*使能时钟*/
	RCC_APB2PeriphClockCmd(RCC_APB2Periph_AFIO|RCC_APB2Periph_GPIOB,ENABLE);
	RCC_APB1PeriphClockCmd(RCC_APB1Periph_TIM3,ENABLE);
	/*重映射PB4->TIM3_CH1;PB5->TIM3_CH2*/
  GPIO_PinRemapConfig(GPIO_Remap_SWJ_JTAGDisable,ENABLE);
  GPIO_PinRemapConfig(GPIO_PartialRemap_TIM3,ENABLE);
	/*配置IO引脚*/
	GPIO_InitTypeDef GPIO_InitStructure;
	GPIO_InitStructure.GPIO_Mode=GPIO_Mode_IPU;//上拉输入
	GPIO_InitStructure.GPIO_Pin=GPIO_Pin_4|GPIO_Pin_5;
	GPIO_InitStructure.GPIO_Speed=GPIO_Speed_50MHz;
	GPIO_Init(GPIOB,&GPIO_InitStructure);
	/*配置定时器为输入捕获*/
	TIM_TimeBaseInitTypeDef TIM_TimeBaseInitStructure;
	TIM_TimeBaseInitStructure.TIM_Period=65536-1;
	TIM_TimeBaseInitStructure.TIM_Prescaler=1-1;
	TIM_TimeBaseInitStructure.TIM_CounterMode=TIM_CounterMode_Up;
	TIM_TimeBaseInitStructure.TIM_ClockDivision=TIM_CKD_DIV1;
	TIM_TimeBaseInitStructure.TIM_RepetitionCounter=0;
	TIM_TimeBaseInit(TIM3,&TIM_TimeBaseInitStructure);
	/*配置编码器模式*/
	TIM_ICInitTypeDef TIM_ICInitStructure;
	TIM_ICStructInit(&TIM_ICInitStructure);
	TIM_ICInitStructure.TIM_Channel=TIM_Channel_1;
	TIM_ICInitStructure.TIM_ICFilter=0xF;
	TIM_ICInit(TIM3,&TIM_ICInitStructure);
	TIM_ICInitStructure.TIM_Channel=TIM_Channel_2;
	TIM_ICInitStructure.TIM_ICFilter=0xF;
	TIM_ICInit(TIM3,&TIM_ICInitStructure);
	
	TIM_EncoderInterfaceConfig(TIM3,TIM_EncoderMode_TI12,TIM_ICPolarity_Rising,TIM_ICPolarity_Rising);
	TIM_Cmd(TIM3,ENABLE);
}


int16_t Encoder_Get(void)
{
	int16_t Temp;
	Temp=TIM_GetCounter(TIM3);
	TIM_SetCounter(TIM3,0);
	return Temp;
}

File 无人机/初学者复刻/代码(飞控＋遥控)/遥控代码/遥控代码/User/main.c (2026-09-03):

/*头文件引用*/
#include "stm32f10x.h"                  // Device header
#include "Delay.h"
#include "OLED.h"
#include "NRF24L01.h"
#include "Rocker_ADC.h"
#include "Timer.h"
#include "Data_Proc.h"
#include "Variable.h"
#include "Key.h"
#include "LED.h"
#include "PowerDetection.h"
#include "Encoder.h"

/*主函数*/
int main(void)
{
	OLED_Init();			//OLED初始化
	NRF24L01_Init();	//无线模块初始化
	Key_Init();       //按键初始化
	Rocker_ADC_Init();//遥感初始化
	Timer_Init();			//定时器初始化
	LED_Init();       //LED初始化
	Encoder_Init();
	

	
	while(1)
	{
		KeyNum();   //按键值处理
		if(LED_Slow_time==0)  {LED_Control();  LED_Slow_time=1;}//LED显示
		if(Proc_Slow_time==0) {Data_Proc();   Proc_Slow_time=1;}//变量处理函数
		if(Disp_Slow_time==0) {Data_Display();Disp_Slow_time=1;}//数据显示函数
		if(Send_Slow_time==0) {Data_Send();   Send_Slow_time=1;}//发送消息
		//if(Receive_Slow_time==0)Data_Receive();
	}
}

/*定时中断，每1ms进一次中断*/ 
void TIM1_UP_IRQHandler(void)
{
	if(TIM_GetITStatus(TIM1,TIM_IT_Update)==SET)
	{
		/*每50ms发送,数据发送给飞控*/
  	if(++Send_Slow_time>4) Send_Slow_time=0;
		if(++Proc_Slow_time>10)  Proc_Slow_time=0;
		if(++Disp_Slow_time>15) Disp_Slow_time=0;
		if(++LED_Slow_time>30) LED_Slow_time=0;
		
		if(++connect_time>500) 
		{	
			connect_time=0;
			connect_value++;
			if(connect_value>200) connect_value=0;
		}
		
		
		TIM_ClearITPendingBit(TIM1,TIM_IT_Update);
	}
}

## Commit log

2026-09-03 无人机文件，只含源码
    [Body.STL, Rotor1.STL, Rotor2.STL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]
2026-09-03 分享工具链接并完善说明文档
2026-09-04 修改文档

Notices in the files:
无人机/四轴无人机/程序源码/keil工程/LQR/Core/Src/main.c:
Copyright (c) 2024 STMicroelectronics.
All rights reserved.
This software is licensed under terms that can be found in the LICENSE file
